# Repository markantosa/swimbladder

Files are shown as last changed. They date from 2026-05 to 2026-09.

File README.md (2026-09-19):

# SwimBladder

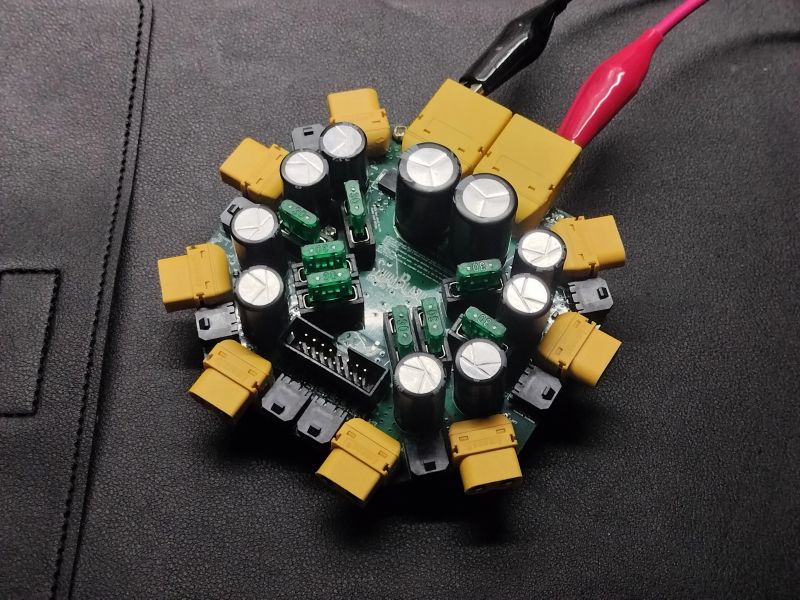
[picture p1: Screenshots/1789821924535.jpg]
Assembled SwimBladder PDB


Power distribution board (PDB) project files for the SwimBladder project.

Silkscreen tag: `SOAR UWU | 8 x T200 | V1.1`

> [!WARNING]
> This board is an unvalidated, untested work in progress (WIP).
> It has not completed electrical, thermal, or in-water system validation.
> Do not treat this design as production-ready hardware.

## Project Status

- Current state: WIP (design in progress)
- Revision: V1.1
- Validation status: not electrically validated
- Test status: not thermally validated, not full-load validated, not field-tested
- Use at your own risk until formal verification is completed

## Repository Contents

- `KiCad Project Files v1.1/` - **Canonical** KiCad project, PCB, schematic, and the
  `SwimBladder Custom Footprints` library. Open `KiCad Project Files v1.1/UWU PDB.kicad_pro`.
- `KiCad Project Files/` - Deprecated earlier project set, kept for history. Do not edit.
- `SwimBladder PDB.kicad_sch` (repo root) - Stale May snapshot, superseded by the schematic
  inside `KiCad Project Files v1.1/`. Do not use.
- `Screenshots/` - Board and schematic screenshots. `v1.1 *.png` are current; the unprefixed
  files are the earlier V1.0 captures.
- `SwimBladderV1.0.step` - 3D board model (V1.0 geometry).
- `Swim_Bladder_Doc_v3_0.pdf` - Full engineering reference and calculations. Component values
  in this PDF predate the V1.1 schematic changes listed below.

## Project Overview

This board is designed as a compact 8-thruster central star-node PDB for Blue Robotics T200
systems with 4S battery input. It is currently in a pre-validation state and should be treated
as a reference design draft.

- System topology: battery -> cable-side main fuse -> optional e-stop/contactor -> dual XT90 input -> central high-current node -> 8 fused ESC branches -> XT60 outputs
- Nominal battery voltage: 14.8 V (4S), full charge: 16.8 V
- Thruster design current: about 25 A each
- Total design current: 200 A (with burst targets up to around 280-300 A)
- Per-branch fuse target: 30 A

## Schematic Summary (V1.1)

### Input / central node
- Dual XT90 input connectors (`J1`, `J19`) feeding one common +VBAT star node, symmetrical wiring for current sharing.
- Bulk capacitance at the node: `C_MAIN1`, `C_MAIN2` = 4700 uF each.
- Input TVS: `D1` (`D_TVS`), 22-24 V standoff class for 4S. Recommended part: SMDJ22A
  (unidirectional, 3 kW, DO-214AB / SMC footprint, `Diode_SMD:D_SMC` or `D_SMC_HandSolder`).
- Rail bleed / discharge: `R_BLEED1` = 22 kOhm. Draws ~0.76 mA / ~13 mW continuously at full
  charge - trivial dissipation for a 0603, well within its power/voltage rating.
- Power/status LED: `D2` (`LED`) with series resistor `R_LED1` = 10 kOhm.

### Per-ESC branch (x8)
- Branch fuse: `F_ESC1..F_ESC8` = 30 A.
- Branch bulk cap: `C_ESC1..C_ESC8` = 1000 uF.
- Branch high-frequency cap: `C_HF1..C_HF8` = 1 uF.
- Output: `J3..J10`, XT60 per branch.
- Branch decoupling is now two caps (1000 uF + 1 uF). The earlier third per-branch cap
  (1 nF high-frequency) has been removed - on a high-current motor branch it contributes
  negligible benefit and can create anti-resonance with the larger caps.

### PWM signal
- 16-pin IDC header `J2` (`Conn_02x08_Odd_Even`, 2x8, 2.54 mm), alternating PWM / GND pins.
  Suggested part footprint: `Connector_IDC:IDC-Header_2x08_P2.54mm_Vertical`.
- Individual PWM channel inputs: `J11..J18` (PWM1..PWM8).
- Per-channel series resistor: `R_PWM1..R_PWM8` = 100 Ohm.
- Per-channel pulldown resistor: `R_PD1..R_PD8` = 10 kOhm.

## Passive Footprint Notes

- PWM channel series resistors (`R_PWM*`): 0402 hand-solder land pattern
  (`Resistor_SMD:R_0402_1005Metric_Pad0.72x0.64mm_HandSolder`) for IDC header pitch.
- All other signal passives (`R_BLEED1`, `R_LED1`, `R_PD*`) and branch HF caps: 0603
  hand-solder (`R_0603_1608Metric_Pad0.98x0.95mm_HandSolder` /
  `C_0603_1608Metric_Pad1.08x0.95mm_HandSolder`).
- Custom / project-specific footprints live in `KiCad Project Files v1.1/SwimBladder Custom Footprints`.

## Key Engineering Notes (from the PDF)

- Architecture: single compact central +VBAT node, not dual banks, for a roughly 90 mm x 90 mm board.
- Safety: main fuse should be upstream on the battery cable (recommended 225-250 A), close to the battery.
- Copper strategy: use a short, wide, via-stitched central polygon (L1 + L3 for +VBAT), and strong common ground return (L2 + L4).
- Copper thickness for the 200 A / 300 A rating: 1 oz (35 um) is not sufficient. Spec 2 oz
  (70 um) minimum on the outer layers, 3 oz preferred, and carry +VBAT and GND on two layers
  each in parallel (~4 oz-equivalent per net) with dense inter-layer via stitching. Treat the
  central node as a plane, not a trace, and size pours/vias for <= 20-30 C rise. Per-branch
  (~25 A): 2 oz outer with ~10-15 mm pour width is adequate.
- Via stitching: use two via classes - large power vias (~1.2 mm pad / 0.6 mm drill or bigger)
  for the +VBAT node and ground return, and a smaller class (~0.6-0.8 mm pad / 0.3-0.4 mm drill)
  for signal-ground / thermal stitching around the PWM header.
- Branch geometry: practical branch widths around 12-15 mm (8-10 mm absolute compact minimum for very short sections).
- Connectors: dual XT90 input for current sharing (symmetrical wiring), XT60 per ESC branch preferred.
- Protection/passives: 22-24 V standoff TVS class for 4S input, bulk capacitance near input/node plus branch-level capacitors.
- Signal: 16-pin IDC PWM header with alternating PWM/GND and per-channel series + pulldown resistors.

## Known Issues / TODO (V1.1)

- No outstanding items. TVS placement, input HF cap grouping, indicator LEDs, and the
  `R_BLEED1` value (now 22 kOhm) have all been resolved.

## Quick Calculation Snapshot

- Per thruster power at 16 V and 25 A: 400 W
- System power for 8 thrusters: 3200 W
- Example central copper section in the doc (50 mm width, 140 um thickness, 25 mm length, one layer):
	- Estimated R ~= 0.0616 mOhm
	- Vdrop at 200 A ~= 0.012 V
	- Copper loss at 200 A ~= 2.46 W

For complete assumptions, formulas, BOM guidance, and test plan, see `Swim_Bladder_Doc_v3_0.pdf`.

## Screenshots (V1.1)

| Assembled Board (1) | Assembled Board (2) |
|---|---|
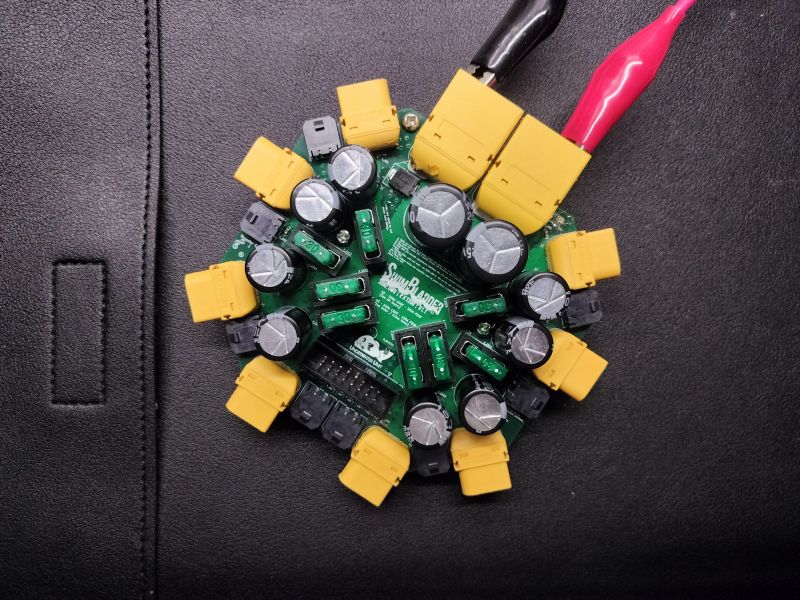
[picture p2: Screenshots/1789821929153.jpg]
Assembled SwimBladder PDB, angle 2
| Assembled SwimBladder PDB, angle 1 |  |

| Routing | 3D Render - Top | 3D Render - Isometric |
|---|---|---|
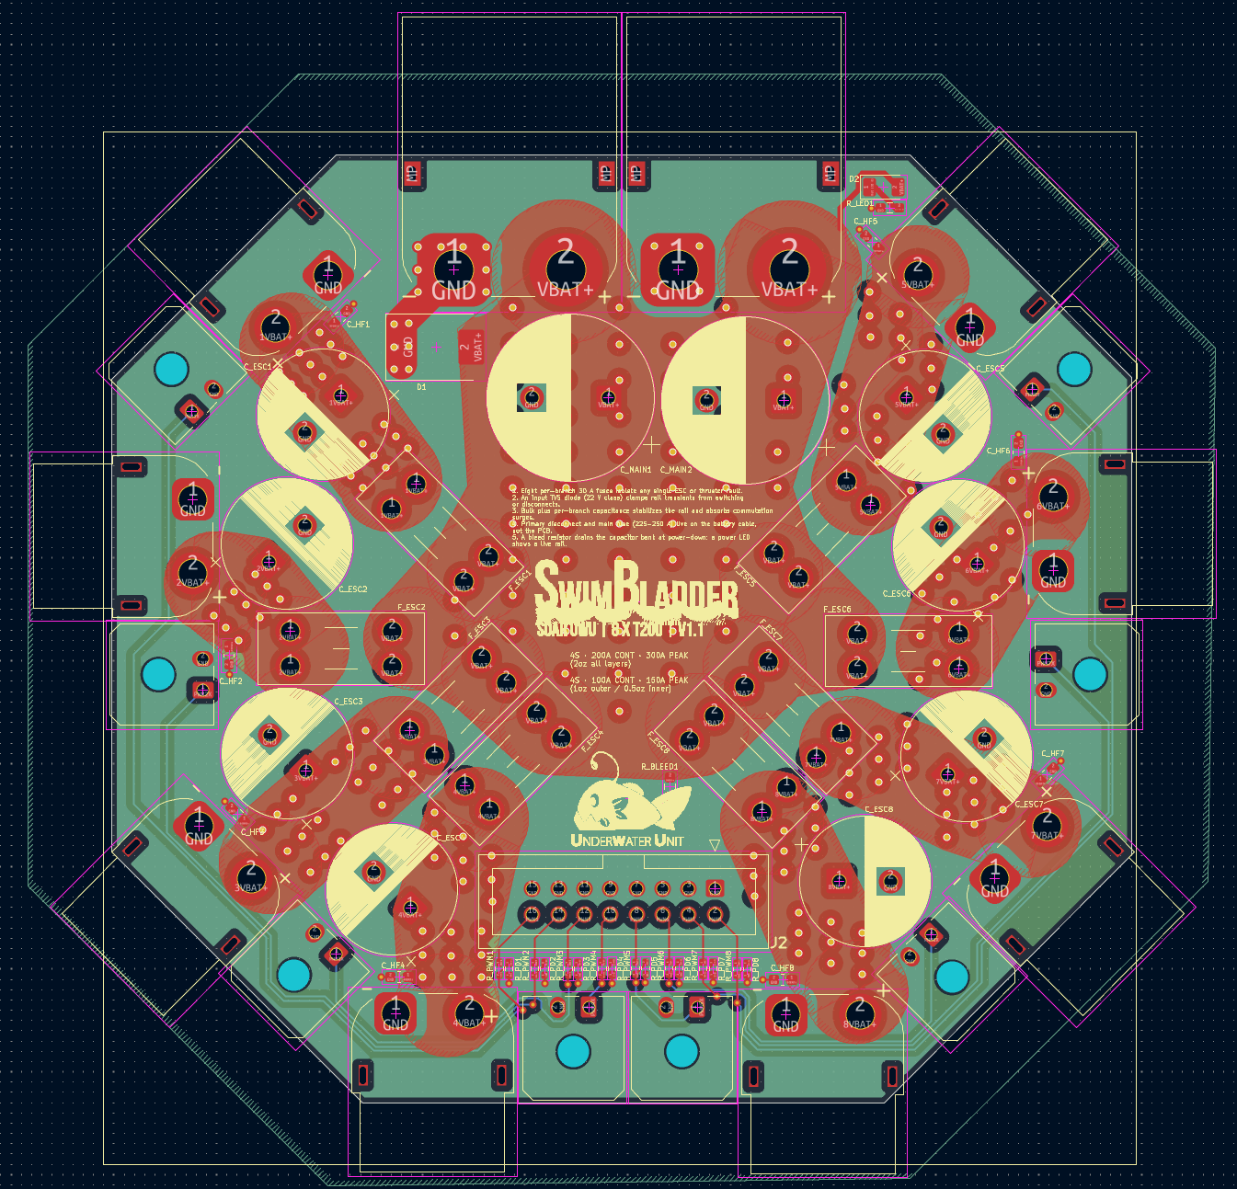
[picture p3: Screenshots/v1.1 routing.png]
V1.1 routing
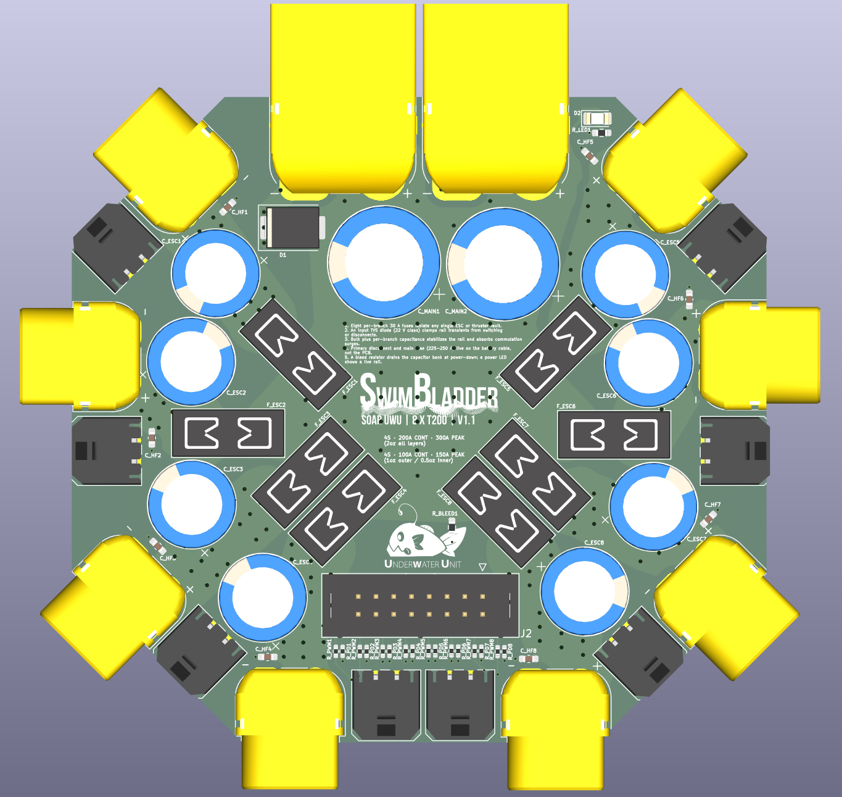
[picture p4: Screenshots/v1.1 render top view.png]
V1.1 render, top view
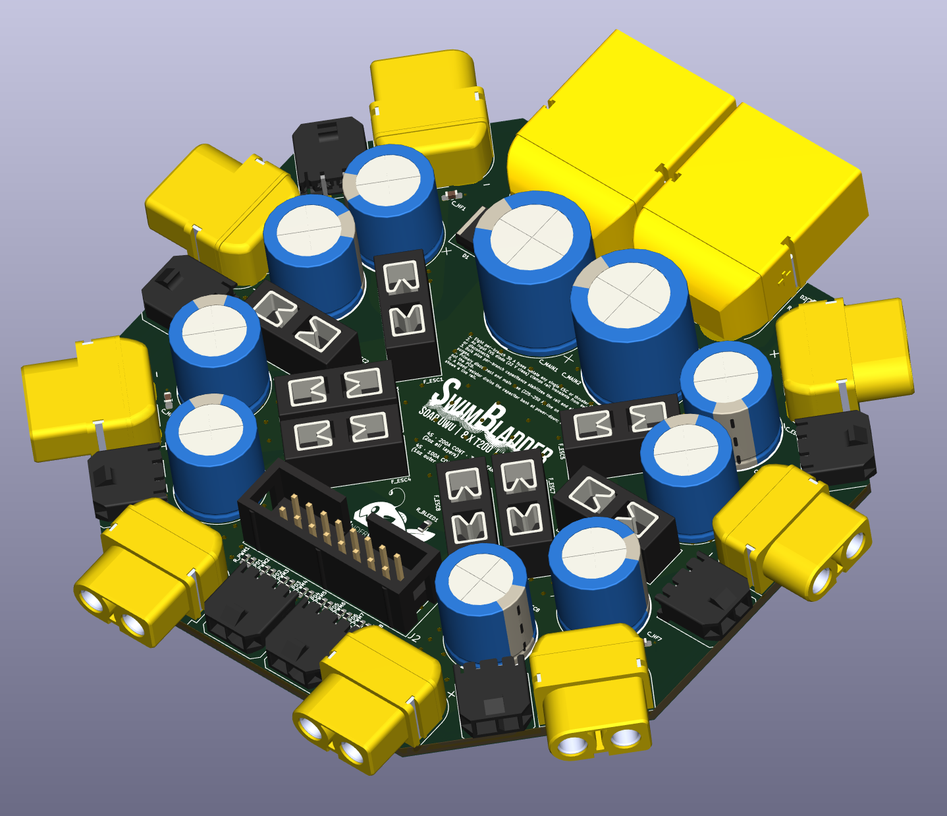
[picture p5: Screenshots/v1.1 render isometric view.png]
V1.1 render, isometric view
|  |  |  |

<sub>Earlier V1.0 captures (`Schematic.png`, `PCB Editor View.png`, `3D View.png`) remain in `Screenshots/` for reference.</sub>

## Getting Started

1. Install KiCad (recommended version 8+).
2. Open the project from `KiCad Project Files v1.1/UWU PDB.kicad_pro`.
3. Review schematic, layout, and engineering assumptions from the PDF before fabrication,
   noting the V1.1 changes and open TODO items above.

## Changelog

### V1.1 (in progress)
- Canonical project files moved to `KiCad Project Files v1.1/`; earlier `KiCad Project Files/`
  and the repo-root `SwimBladder PDB.kicad_sch` are deprecated.
- Added `SwimBladder Custom Footprints` library.
- Main bulk capacitance specified as `C_MAIN1/2` = 4700 uF each.
- Removed the 1 nF per-branch decoupling cap; branches now use 1000 uF + 1 uF only.
- PWM front-end defined: `R_PWM*` = 100 Ohm series, `R_PD*` = 10 kOhm pulldown, inputs `J11..J18`.
- Added rail bleed resistor `R_BLEED1` (value still a placeholder) and status LED `D2` / `R_LED1`.
- Input TVS `D1` present; placement correction pending (see Known Issues).

### V1.0
- Initial 8-branch central star-node PDB layout.

## Procurement (2-board build)

Bare PCB via JLCPCB; most components via LCSC (`SwimBladder_LCSC_BatchBOM_v1.1.csv`); full
reference BOM in `SwimBladder_BOM_v1.1.csv`. JLCPCB and LCSC ship separately even though they're
sister companies - no combined-box option outside of paying for JLC's PCBA assembly service.

### Still need to source separately (not in the LCSC batch order)
- [ ] `R_BLEED1`, 22k Ohm, 0603 (LCSC C114065) - MOQ is Min:100/Mult:100, not worth it for ~3
  pieces; ask around for spares or buy loose.
- [ ] `R_LED1` + `R_PD1..R_PD8`, 10k Ohm, 0603 (LCSC C98220) - same MOQ issue, ~23 pieces needed.
- [ ] 30 A mini blade fuse elements (x16) for `F_ESC1..F_ESC8` - these plug into the Keystone 3568
  holder (which is in the LCSC order) but the fuse element itself isn't an LCSC/electronics-
  distributor item; source from an automotive parts store or RC supplier.
- [ ] `F_ESC1..F_ESC8` fuseholders, Keystone 3568 (x8) - LCSC C5249699 was out of stock, dropped
  from the batch order; source from Digi-Key/Mouser instead.

### Already owned, not in the order
- `D2` status LED
- `J2` IDC 2x08 header
- `R_PWM1..R_PWM8`, 100 Ohm, 0402 (from sample book)

## License

This project is licensed under the MIT License. See the LICENSE file for details.

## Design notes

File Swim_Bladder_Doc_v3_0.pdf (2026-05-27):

Compact 8-Thruster Star-Node T200 PDB Technical Specification | 1

## Swim Bladder: 8-Thruster Central Star-Node PDB

Technical Specification for 8× Blue Robotics T200 + Basic ESC System

Power Source: 4S battery direct input, 14.8 V nominal / 16.8 V fully charged Architecture: Cable-side main fuse, dual XT90 input, one compact central high-current node, eight fused ESC branches

Contents

1 Purpose of This Architecture | 2
2 Electrical Assumptions | 2
3 High-Level System Architecture | 3
4 Recommended Physical Layout | 3
5 Fuse Architecture | 4
6 PCB Stack-Up | 5
7 Copper Geometry and Current Carrying Design | 5
8 Voltage Drop and Loss Estimates | 6
9 Via Specification | 7
10 Connector Recommendations | 7
11 Passive Components and Protection | 8
12 PWM and Signal Architecture | 9

Compact 8-Thruster Star-Node T200 PDB Technical Specification | 2
13 Recommended BOM | 9
14 Layout Checklist | 9
15 Test Plan | 10
16 Final Design Summary | 11

### 1 PURPOSE OF THIS ARCHITECTURE

This document describes a compact high-current power distribution board for an 8-thruster ROV system using eight Blue Robotics T200 thrusters and eight Basic ESCs powered directly from a 4S lithium battery. The previous dual-bank architecture was useful for larger boards, but for a compact board of approximately 90 mm by 90 mm, the two bank nodes physically merge into the same central copper region.

The recommended compact architecture is therefore a single central star node: the battery input feeds a very short, wide, heavily via-stitched copper island, and all eight branch fuses are placed close to that node.

Recommended compact architecture:

Battery -> cable-side main fuse -> e-stop/contactor -> dual XT90 input -> short central 200 A node
-> eight 30 A branch fuses
-> eight XT60 ESC outputs

Design Note: The board is no longer treated as two separated 4-thruster banks. Instead, it is treated as one compact star PDB. This is acceptable because the main fuse is moved upstream on the cable and the high-current PCB region is extremely short.

Warning: This architecture depends on having a proper upstream main fuse near the battery. Without a main cable-side fuse, the central node and PCB input copper before the branch fuses would be insufficiently protected.

### 2 ELECTRICAL ASSUMPTIONS

A 4S lithium battery is assumed:

Vnominal ≈ 14.8 V | (1)
Vfull = 4 × 4.2 V = 16.8 V | (2)

Use conservative T200 current at the 16 V class:

Ithruster,max ≈ 25 A | (3)

For eight thrusters:

Itotal,max = 8 × 25 A = 200 A | (4)

Recommended system design target:

Icentral node,continuous design = 200 A–220 A | (5)
Icentral node,burst design = 280 A–300 A | (6)
Ibranch,design = 30 A | (7)

Per-thruster electrical power at 16 V:

Pthruster = V I = 16 V × 25 A = 400W | (8)

Compact 8-Thruster Star-Node T200 PDB Technical Specification | 3

Whole system:

Psystem = 8 × 400W = 3200W | (9)

### 3 HIGH-LEVEL SYSTEM ARCHITECTURE

### 3.1 Recommended Power Tree

4S Battery, 14.8 V nominal / 16.8 V full
[Main fuse on cable, near battery: 225-250 A typical]
[Electrical E-stop / DC contactor, optional but recommended] |
[Dual XT90-S or dual XT90 input to PCB]
[Short central 200 A star node]
|-- 30 A fuse -- XT60 -- ESC1 -- T200 |-- 30 A fuse -- XT60 -- ESC2 -- T200 |-- 30 A fuse -- XT60 -- ESC3 -- T200 |-- 30 A fuse -- XT60 -- ESC4 -- T200 |-- 30 A fuse -- XT60 -- ESC5 -- T200 |-- 30 A fuse -- XT60 -- ESC6 -- T200 |-- 30 A fuse -- XT60 -- ESC7 -- T200 ‘-- 30 A fuse -- XT60 -- ESC8 -- T200

### 3.2 Core Layout Principle

The central node architecture minimizes PCB area by reducing the length of copper carrying full system current.

Bad compactness:
Battery input -> long 200 A spine -> ESC1 -> ESC2 -> ... -> ESC8

Good compactness:
Battery input -> short 200 A copper node -> eight short 30 A branches

Warning: The central node should be designed as a copper bus plate built into the PCB, not as a normal routed trace. It must be short, wide, multi-layered, heavily via-stitched, and thermally tested.

### 4 RECOMMENDED PHYSICAL LAYOUT

### 4.1 Top-Level Board Layout

For a compact 90 mm by 90 mm PCB, place the dual XT90 input close to the center or edge-center of the board, then place the eight branch fuse inputs as close as possible around the central node.

Top view concept, compact central-node version:

DUAL XT90 BATTERY INPUT
XT90-A XT90-B
\ /
\ /
+---------------------+
| CENTRAL 200 A NODE |
+---------------------+
/ / / | \ \ \
F1 F2 F3 F4 F5 F6 F7/F8
X1 X2 X3 X4 X5 X6 X7/X8
E1 E2 E3 E4 E5 E6 E7/E8

X1-X8 = XT60 branch outputs
E1-E8 = ESC power leads
PWM IDC connector should sit near a quiet board edge.

### 4.2 Central Node Detail

The central node is a compact copper island connecting the dual XT90 positive inputs to all eight branch fuse inputs.

Dual XT90 positive pads
+----------------+
| 200 A NODE | short, wide, via-stitched copper island
+----------------+
/ / / / \ \ \ \
F1 F2 F3 F4 F5 F6 F7 F8
XT60 branch outputs to ESCs

Compact 8-Thruster Star-Node T200 PDB Technical Specification | 4

Design Note: The branch split should happen immediately after the dual XT90 input. The central node should feed all fuse input pads directly with no thin neck-downs.

### 4.3 Ground Layout

The positive side uses a central star node and individual branch fuses. The ground side should be a common, low-impedance return system.

Battery - from dual XT90 input
+-- common GND plane / GND node
|-- XT60 negative return for ESC1-ESC8
‘-- flight controller signal ground reference

Design Note: Use common GND across the board. ESC PWM signals require a common reference to the flight controller. Do not isolate grounds unless there is a specific measurement reason.

### 5 FUSE ARCHITECTURE

### 5.1 Fuse Philosophy

Recommended protection hierarchy:

- main fuse on cable, close to the battery,
- optional contactor or electrical e-stop before the PCB,
- one branch fuse per ESC on the PCB.

### 5.2 Cable-Side Main Fuse

Because the PCB no longer contains bank fuses, the upstream cable-side main fuse becomes mandatory.

Recommended:

Imain fuse = 225 A–250 A | (10)

Placement:

Battery + → main fuse → e-stop/contactor → PCB input | (11)

Recommended fuse type:

- ANL fuse,
- MEGA fuse,
- high-current marine or EV-style battery fuse holder.

Warning: The main fuse must be close to the battery, not only close to the PCB. Its job is to protect the battery cable, e-stop wiring, PCB input, and central node from catastrophic shorts before the branch fuses.

### 5.3 Branch Fuse Sizing

Each ESC branch:

Ibranch actual ≈ 24 A–25 A | (12)
IESC class ≈ 30 A | (13)

Recommended:

Ibranch fuse = 30 A | (14)

Recommended fuse holder:

- Keystone 3568 mini blade fuse holder, PCB-mounted, or
- Littelfuse FLR 178.6165 ATO holder with caution, or
- off-board inline ATO/ATC fuse holder for better thermal margin.

Warning: Do not increase branch fuses above 30 A unless the ESC, wiring, connector, and thermal path are explicitly validated. If nuisance blowing occurs, investigate throttle limiting, cooling, and fuse time-current curves first.

Compact 8-Thruster Star-Node T200 PDB Technical Specification | 5

### 6 PCB STACK-UP

Recommended 4-layer stack-up:

Table 1: Recommended 4-Layer Stack-Up

Layer | Function
L1 / F.Cu | +VBAT central node and branch fuse input/output pours
L2 / In1.Cu | GND high-current return plane
L3 / In2.Cu | +VBAT central node and branch pours, stitched to L1
L4 / B.Cu | GND plane + PWM / telemetry / low-current signal routing
+V BAT path : L1 + L3 | (15)
GND path : L2 + L4 | (16)

Design Note: Use L1 and L3 in parallel for the central +VBAT node and branch paths. Use L2 and L4 in parallel for the common GND return.

### 7 COPPER GEOMETRY AND CURRENT CARRYING DESIGN

### 7.1 Estimation Method

Use IPC-style estimation:

I = k∆T

bA

c
(17)

Rearranged:

A =

I
k∆Tb

1/c
(18)

Common constants:

kexternal = 0.048, | kinternal = 0.024, | b = 0.44, | c = 0.725 | (19)

For 4 oz copper:

| tCu ≈ 140 µm | | | (20)

### 7.2 Branch Width

Each branch is designed for:

Ibranch design = 30 A | (21)

Estimated minimum 4 oz external copper width at approximately 20 ◦C rise:

W30A ≈ 5.4 mm | (22)

Recommended practical branch pour width:

Wbranch = 12 mm–15 mm | (23)

Absolute compact minimum for very short branch routes:

Wbranch,min ≈ 8 mm–10 mm | (24)

Compact 8-Thruster Star-Node T200 PDB Technical Specification | 6

### 7.3 Central Node Size

The central node carries full system current only over a very short distance.

Central node design target:

Inode,max = 200 A | (25)
Inode,design = 200 A–220 A | (26)
Inode,burst = 280 A–300 A | (27)

For a long one-layer 4 oz trace, 200 A would require a very large width. However, this board uses a compact multi-layer copper island rather than a long trace. The design goal is therefore:

Table 2: Recommended Central Node Geometry

Parameter | Recommendation
Node type | Large compact copper polygon, not a routed trace
Node location | Immediately after dual XT90 input pads
Node layers | L1 + L3 parallel +VBAT copper
Node length | As short as possible; preferably below 20 mm–30 mm before branch split
Node area | Maximize available area around XT90 and fuse inputs
Minimum effective copper section | Avoid any local neck-down below approximately 50 mm equivalent where full
current flows
Via stitching | Dense via field across the node and around every input/fuse pad
Branch exits | Eight direct short branch pours from node to branch fuses
Copper exposure | Optional exposed copper/solder reinforcement on central node if fabrication al-
lows

Warning: Do not draw a thin trace from the XT90 input to the fuse inputs. The central node should be a filled polygon surrounding the input pads and fuse input pads.

### 7.4 Input Connector Sharing

Using dual XT90 inputs helps share current between two physical connectors. The two XT90 positive pads should join immediately into the central node. The two XT90 negative pads should join immediately into the common GND plane.

Iper XT90,ideal ≈

200 A
2
= 100 A | (28)

Warning: Current sharing between two connectors is not automatically perfect. Keep both input paths sym-metrical, short, and wide. Use the same wire gauge and length for both XT90 feeds if possible.

### 8 VOLTAGE DROP AND LOSS ESTIMATES

For a short central node, losses can be manageable despite high current. Example: 50 mm effective-width, 140 µm thick, 25 mm long copper section on one layer:

A = 0.050 × 0.000140 = 7.0 × 10⁻⁶ m² (29)

R =

1.724 × 10⁻⁸ × 0.025
7.0 × 10⁻⁶

(30)

≈ 0.0000616 Ω = 0.0616 mΩ | (31)

At 200 A:

Vdrop = IR = 200 × 0.0000616 ≈ 0.012 V | (32)

Ploss = I

2R = 200² × 0.0000616 ≈ 2.46W | (33)

Compact 8-Thruster Star-Node T200 PDB Technical Specification | 7

With L1 and L3 sharing current, effective resistance can be lower if the vias are dense and current spreads well. In practice, pad bottlenecks, solder joints, fuse holders, and connector interfaces may dominate heating.

Design Note: The central-node layout reduces heating mainly by reducing the length of copper that carries full system current. After the node splits, each branch only carries approximately 25 A–30 A.

### 9 VIA SPECIFICATION

### 9.1 Recommended Via Dimensions

Table 3: Recommended Via Dimensions

Parameter | Recommended | Notes
Via drill | 0.5 mm–0.6 mm | Larger preferred if fab allows
Via diameter | 1.0 mm–1.2 mm | Use for high-current stitching
Same-net via pitch | 1.5 mm–2.5 mm | Use arrays across node and branches
Different-net clearance | ≥ 1.0 mm preferred | Especially near node and connector regions

### 9.2 Recommended Via Counts

Table 4: Via Counts for Compact Central-Node Design

Location | +VBAT Vias | GND Vias | Notes
Dual XT90 input region | 80+ total | 80+ total | Around both positive and negative input pads
Central 200 A node | 100+ distributed | 100+ nearby GND stitching | Dense via field across the node
Each branch exit from node | 8–12 | 8–12 | Per branch exit
Each ESC branch | 12–20 | 12–20 | Per branch
Each XT60 connector region | 12–16 | 12–16 | Prevent pad bottlenecks
Capacitor region | 6–10 | 6–10 | Short path to planes
TVS region | 12–20 | 12–20 | Low-impedance clamp path

Warning: Distribute vias across the node. Do not place only one via cluster; the goal is current spreading between L1 and L3 across the whole copper node.

### 10 CONNECTOR RECOMMENDATIONS

### 10.1 Main Battery Input

For compactness, the current design uses dual XT90 input connectors. This is acceptable if the upstream wiring is symmetric and the main fuse is on the cable.

Table 5: Main Input Connector Options

Connector | Verdict
Dual XT90-S | Good compact option if current shares symmetrically.
QS8-S | Preferred single high-current connector if packaging allows.
AS150 or AS150U | Good high-current anti-spark option.
M6 or M8 ring lug / stud input | Most mechanically robust option, but larger.
Single XT90-S | Not preferred for full 8-thruster 4S operation.

### 10.2 ESC Output Connectors

At 4S, each ESC branch is expected to operate around 25 A and should be designed around 30 A. XT60 is preferred for each branch output.

Compact 8-Thruster Star-Node T200 PDB Technical Specification | 8

Table 6: ESC Output Connector Options

Connector | Verdict
XT60 | Preferred for branch-level margin and lower connector heating.
XT30 | Borderline; use only if short, well-soldered, cooled, and thermally validated.
Direct terminal, ring, or spade | Mechanically robust if packaging allows.

Design Note: Horizontal XT60 connectors may be placed directly beside the central node area, but each XT60 must be behind its own branch fuse. Do not feed multiple ESCs through one XT60.

### 11 PASSIVE COMPONENTS AND PROTECTION

### 11.1 Capacitors

Recommended capacitor placement follows the central-node architecture:

- main bulk capacitor near the dual XT90 input or central node,
- branch bulk capacitors near each XT60/ESC output,
- ceramic capacitors near branch outputs for high-frequency decoupling.

Main node capacitance:

Cmain bulk = 2200 µF–4700 µF, 35 V or 50 V | (34)

Space-saving alternatives:

Cmain alternative = 2 × 2200 µF or 3 × 1500 µF | (35)

Per ESC branch:

Cbranch bulk = 470 µF–1000 µF, 35 V or 50 V | (36)
CHF = 1 µF, 50 V, X7R | (37)
Cdecouple = 100 nF, 50 V, X7R | (38)

Recommended compact capacitor footprints:

- 1000 µF, 35 V: Capacitor_THT:CP_Radial_D8.0mm_P3.50mm if exact part fits, otherwise D10.0mm_P5.00mm;
- 4700 µF, 35 V: Capacitor_THT:CP_Radial_D12.5mm_P5.00mm if exact part fits;
- ceramic capacitors: Capacitor_SMD:C_1206_3216Metric preferred.

### 11.2 TVS Protection

For a 4S pack, the TVS must not conduct during normal fully charged battery voltage of 16.8 V. Recommended:

VTVS standoff = 22 V–24 V | (39)

Recommended part class:

- SMCJ24A or similar for compact protection,
- SM8S24A or similar for stronger surge margin if space allows.

KiCad symbol and footprint:

- symbol: Device:D_TVS,
- footprint: Diode_SMD:D_SMC for SMCJ class.

Wiring:

TVS cathode → +V BAT | (40)
TVS anode → GND | (41)

Warning: The TVS should be close to the input/central node, but it must not create a narrow bottleneck in the main current path. Prioritize a clean central copper node.

Compact 8-Thruster Star-Node T200 PDB Technical Specification | 9

### 11.3 Bleeder Resistor

Recommended:

Rbleeder = 10 kΩ–47 kΩ | (42)
Prating = 0.25W minimum | (43)

At 16.8 V and 10 kΩ:

P =

16.8

2
10000
= 0.028W | (44)

### 11.4 Power Indicator LED

LED resistor at full charge for approximately 2 mA:

R =

16.8 − 2
0.002
= 7.4 kΩ | (45)

Recommended:

RLED = 6.8 kΩ–10 kΩ, 0.25W | (46)

### 12 PWM AND SIGNAL ARCHITECTURE

PWM is low-current and distributed through one 16-pin IDC connector.

Table 7: 16-Pin IDC PWM Pinout

Pin | Signal | Pin | Signal
1 | PWM1 | 2 | GND
3 | PWM2 | 4 | GND
5 | PWM3 | 6 | GND
7 | PWM4 | 8 | GND
9 | PWM5 | 10 | GND
11 | PWM6 | 12 | GND
13 | PWM7 | 14 | GND
15 | PWM8 | 16 | GND

Per PWM channel:

Rseries = 100 Ω–220 Ω | (47)
Rpulldown = 10 kΩ | (48)

Recommended:

Rseries = 100 Ω, | Rpulldown = 10 kΩ | (49)

Design Note: Keep the IDC connector near a quiet board edge. Route PWM away from the dual XT90 input, TVS diode, fuse input pads, and central node.

### 13 RECOMMENDED BOM

### 13.1 Power Path BOM

### 13.2 Passive and Protection BOM

### 13.3 Signal BOM

### 14 LAYOUT CHECKLIST

Compact 8-Thruster Star-Node T200 PDB Technical Specification | 10

Table 8: Power Path Components for Compact Central-Node Design

Ref. | Component | Rating / Value | Qty
J-IN-A/B | Main input connectors | Dual XT90-S or dual XT90 | 2
F-MAIN | Cable-side main fuse | 225 A–250 A, DC-rated | 1 off-PCB
K-ESTOP | Optional contactor / e-stop | 200 A+ DC contactor, 12 V coil typical | 1 off-PCB
J-ESC-1–8 | ESC output connector | XT60 preferred; XT30 derated | 8
F-ESC-1–8 | Branch fuse | 30 A mini blade / ATO / ATC | 8

Table 9: Passive and Protection Components

Ref. | Component | Rating / Value | Qty
C-MAIN | Main bulk capacitor | 2200 µF–4700 µF, 35 V or 50 V | 1–2
C-ESC-1–8 | Branch electrolytic capacitor | 470 µF–1000 µF, 35 V or 50 V | 8
C-HF-1–8 | Ceramic capacitor | 1 µF, 50 V, X7R | 8
C-DEC-1–8 | Ceramic capacitor | 100 nF, 50 V, X7R | 8
D-TVS-MAIN | Main TVS diode | 22 V–24 V standoff, high pulse power | 1
R-BLEED | Bleeder resistor | 10 kΩ, 0.25W | 1
LED-MAIN | Main power LED | suitable indicator LED | 1
R-LED | LED resistor | 6.8 kΩ–10 kΩ, 0.25W | 1

Table 10: PWM Signal Components

Ref. | Component | Rating / Value | Qty
J-PWM | IDC connector | 2 by 8, 16-pin | 1
R-PWM-1–8 | Series resistor | 100 Ω | 8
R-PD-1–8 | Pull-down resistor | 10 kΩ | 8
D-ESD | Optional ESD diode array | Low-capacitance signal ESD | 1–2
- Cable-side main fuse is included near the battery.
- E-stop / contactor is upstream of PCB if used.
- Dual XT90 inputs are short and symmetric.
- Central node is a large filled polygon, not a trace.
- No long 200 A spine exists.
- All branch fuse inputs connect directly to the central node.
- Eight branch fuses are placed close to the node.
- Each branch fuse is rated 30 A.
- Each XT60 is behind its own branch fuse.
- Branch pours are 12 mm–15 mm where possible.
- Absolute branch bottlenecks are not below 8 mm– 10 mm unless extremely short.
- High-current pads use direct copper connection.
- No thermal reliefs on XT90, fuse, XT60, TVS, or bulk capacitor pads.
- L1/L3 +VBAT copper is heavily stitched.
- L2/L4 GND copper is heavily stitched.
- GND is common and low impedance.
- TVS does not block or neck the main current path.
- PWM traces stay away from input, fuses, TVS, and central node.
- IDC pinout alternates PWM/GND.
- Cable strain relief is included for XT90 and XT60 wiring.
- Thermal camera test is planned.

### 15 TEST PLAN

### 15.1 Continuity Test

Before applying power:

- verify +VBAT to GND is not shorted,
- verify each branch positive passes through its branch fuse,
- verify each ESC negative returns to common GND,

Compact 8-Thruster Star-Node T200 PDB Technical Specification | 11
- verify dual XT90 positive inputs join at the central node,
- verify dual XT90 negative inputs join at common GND,
- verify PWM lines are not shorted to +VBAT,
- verify IDC pinout.

### 15.2 Low-Current Power-Up

Use a current-limited bench supply:

Vsupply = 16 V–16.8 V | (50)
Ilimit = 0.5 A–1 A | (51)

Check:

- power LED turns on,
- no unexpected heating,
- capacitors charge normally,
- TVS does not heat during normal supply voltage.

### 15.3 Progressive Load Test

Test progressively:

1. 1 ESC at low throttle.
2. 1 ESC at high throttle.
3. 2 ESCs.
4. 4 ESCs.
5. 8 ESCs with controlled ramp.

Measure:

- input current,
- current through each XT90 input if possible,
- voltage drop from XT90 input to each XT60 connector,
- temperature of central node,
- temperature of branch fuse holders,
- temperature of XT60 pads,
- temperature of XT90 pads,
- TVS temperature,
- PWM stability during throttle changes.

Suggested pass criteria:

- no copper node above approximately 60 ◦C–70 ◦C during expected operation,
- no connector or fuse holder hotspot significantly above surrounding copper,
- voltage drop from input to XT60 branch preferably below 100 mV–200 mV under heavy load,
- dual XT90 inputs share current reasonably well,
- no PWM glitches during high-current throttle changes.

### 16 FINAL DESIGN SUMMARY

Design Note: For a compact 90 mm by 90 mm PCB, the single central star-node architecture is more practical than forcing two artificial banks. The safety condition is that the main fuse must be on the cable near the battery, while each ESC branch remains individually fused on the PCB.

Compact 8-Thruster Star-Node T200 PDB Technical Specification | 12

Table 11: Recommended Parameters for Compact Central Star-Node Architecture

Item | Recommendation
Battery input | 4S lithium, 14.8 V nominal, 16.8 V full
Architecture | One compact central 200 A star node with eight fused branches
Board size target | Approximately 90 mm by 90 mm
PCB | 4-layer, 4 oz copper preferred
Stack-up | L1 +VBAT, L2 GND, L3 +VBAT, L4 GND + PWM/signal
Main input | Dual XT90-S or dual XT90, symmetric wiring required
Main fuse | Off-PCB cable-side fuse, 225 A–250 A
E-stop | Off-PCB contactor or manual isolator before PCB
Branch fuses | 8× 30 A mini blade / ATO / ATC fuses
ESC outputs | XT60 preferred; XT30 only if derated and thermally validated
Central node | Short, wide copper polygon directly after dual XT90 input
Node length | Preferably below 20 mm–30 mm before branch split
Branch width | 12 mm–15 mm per ESC branch; 8 mm–10 mm compact minimum
Vias | 0.5 mm–0.6 mm drill / 1.0 mm–1.2 mm diameter preferred
Central node vias | 100+ +VBAT vias distributed across central node
Branch vias | 12–20 vias per branch per net
Main capacitance | 2200 µF–4700 µF, 35 V or 50 V
Branch capacitance | 8× 470 µF–1000 µF; 8× 1 µF; 8× 100 nF
TVS | Main TVS, 22 V–24 V standoff, SMCJ or stronger
PWM connector | 16-pin IDC, alternating PWM/GND
PWM passives | 100 Ω series + 10 kΩ pulldown per PWM channel
ESC cooling | External aluminium heat block

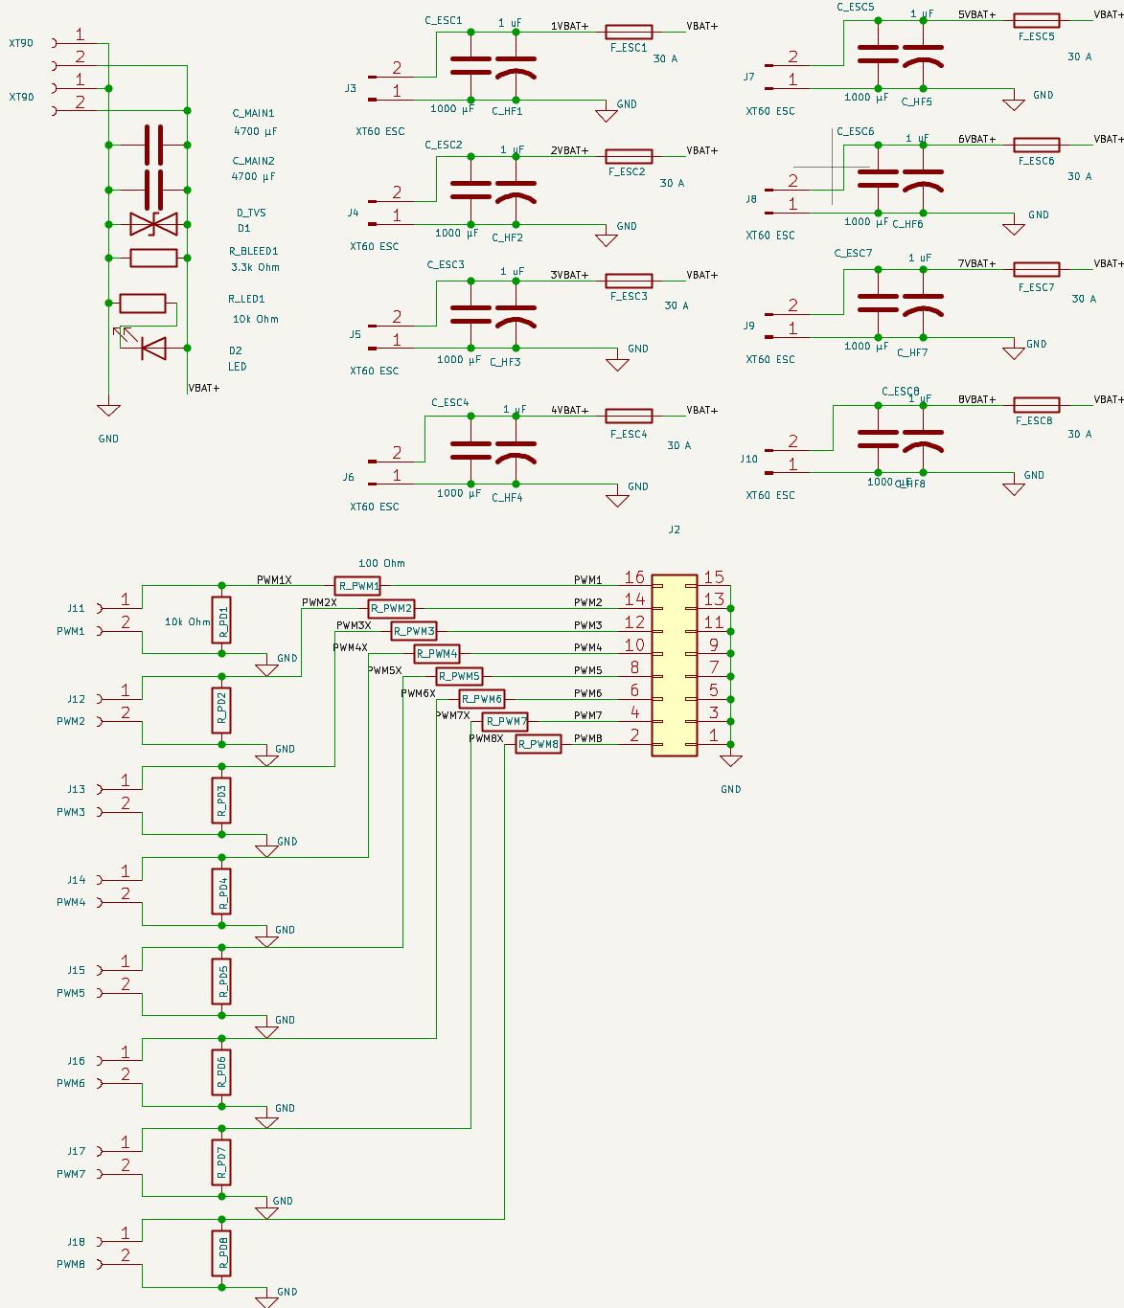
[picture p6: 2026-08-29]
Screenshots/v1.1 schematic.png

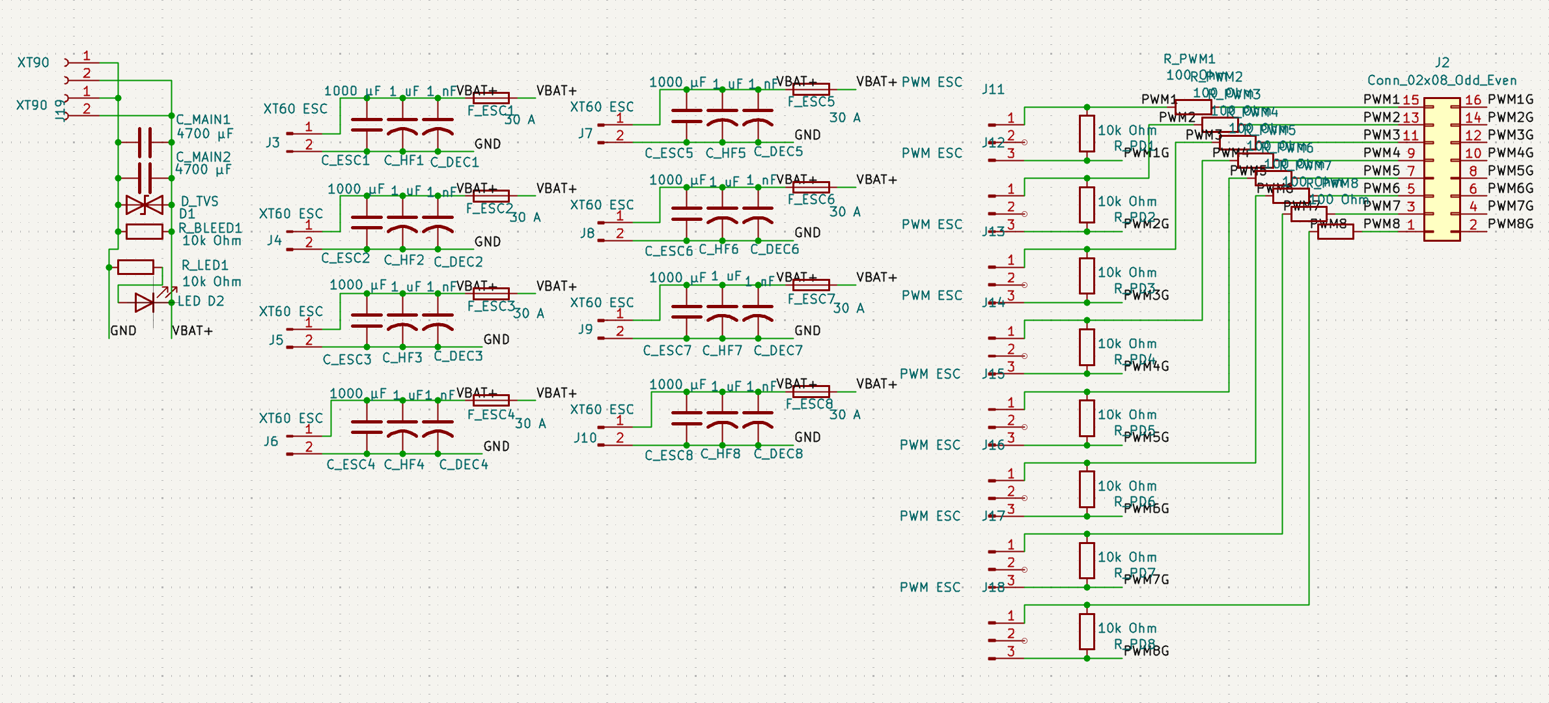
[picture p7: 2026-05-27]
Screenshots/Schematic.png

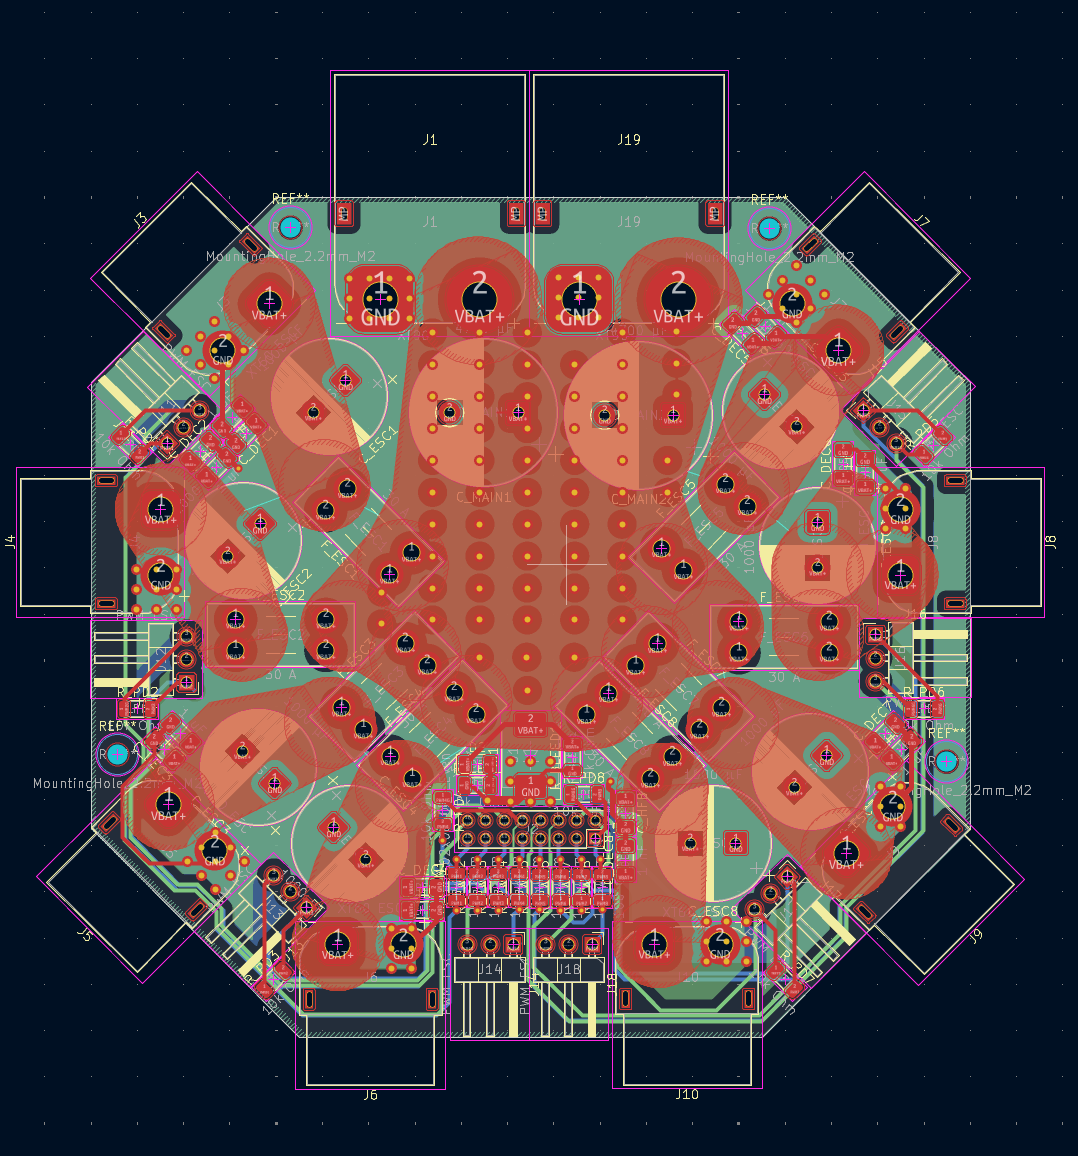
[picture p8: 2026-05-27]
Screenshots/PCB Editor View.png

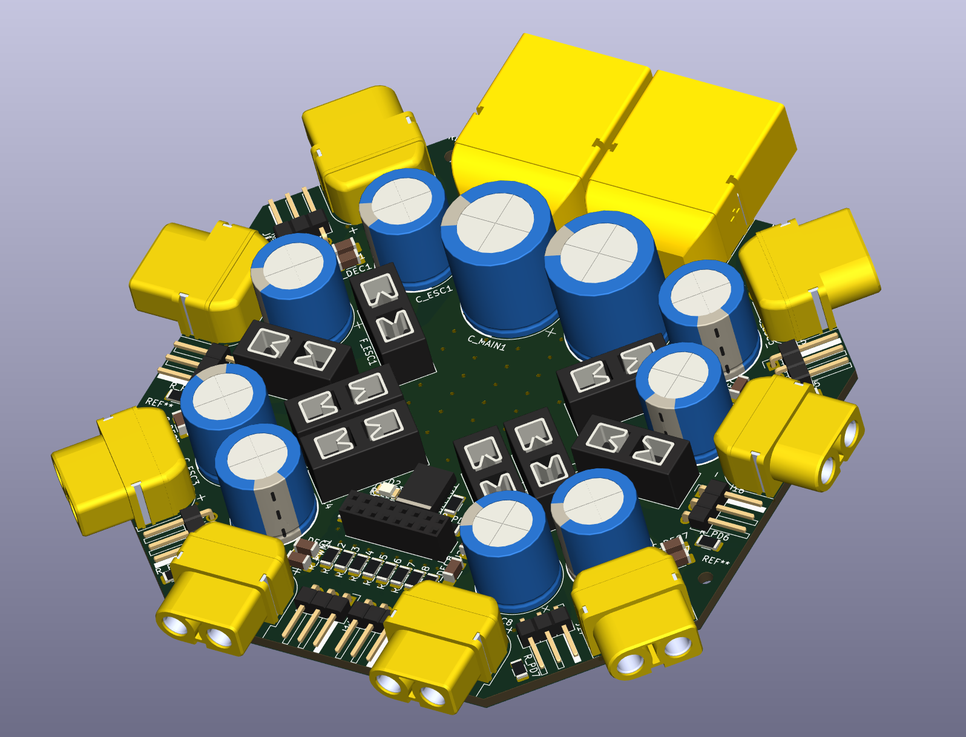
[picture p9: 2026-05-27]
Screenshots/3D View.png

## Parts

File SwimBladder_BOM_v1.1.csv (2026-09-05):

Designators | Value | Footprint | Qty per board | Order Qty (2 boards + margin/MOQ) | Package/Type | Source
J1, J19 | AMASS XT90PW-M.G.Y | Connector_AMASS:AMASS_XT90PW-M_1x02_P10.90mm_Horizontal | 2 | 4 | THT panel connector | LCSC C3040689
J3, J4, J5, J6, J7, J8, J9, J10 | AMASS XT60PW-F | Connector_AMASS:AMASS_XT60PW-F_1x02_P7.20mm_Horizontal | 8 | 16 | THT panel connector | LCSC C428722
J11, J12, J13, J14, J15, J16, J17, J18 | Molex 436500201 (Micro-Fit 3.0 43650-0200) | Connector_Molex:Molex_Micro-Fit_3.0_43650-0200_1x02_P3.00mm_Horizontal | 8 | 16 | THT 2-pin header | LCSC C587649
J2 | IDC Header 2x08 | Connector_IDC:IDC-Header_2x08_P2.54mm_Vertical | 1 | 0 | THT 16-pin IDC | ALREADY OWNED - not ordering
D1 | SMDJ22A TVS diode (5.0SMDJ22A/TR13 - Brightking) | Diode_SMD:D_SMC | 1 | 2 | SMC | LCSC C522679
D2 | Status LED | LED_SMD:LED_0805_2012Metric | 1 | 0 | 0805 | ALREADY OWNED - not ordering
C_MAIN1, C_MAIN2 | 4700uF 25V (EWH1EM472L25OT - AISHI) | Capacitor_THT:CP_Radial_D16.0mm_P7.50mm | 2 | 5 | Radial THT | LCSC C2843670 (Min:5 Mult:5, rounded up from 4)
C_ESC1, C_ESC2, C_ESC3, C_ESC4, C_ESC5, C_ESC6, C_ESC7, C_ESC8 | 1000uF 35V (35YXJ1000M12.5X20 - Rubycon) | Capacitor_THT:CP_Radial_D12.5mm_P5.00mm | 8 | 20 | Radial THT | LCSC C88743 (Min:5 Mult:5, rounded up from 16)
C_HF1, C_HF2, C_HF3, C_HF4, C_HF5, C_HF6, C_HF7, C_HF8 | 1uF 25V X7R (CL10B105KA8NNNC - Samsung) | Capacitor_SMD:C_0603_1608Metric_Pad1.08x0.95mm_HandSolder | 8 | 20 | 0603 | LCSC C29936 (Min:10 Mult:10)
F_ESC1, F_ESC2, F_ESC3, F_ESC4, F_ESC5, F_ESC6, F_ESC7, F_ESC8 (holder) | Keystone 3568 mini blade fuseholder | Fuse:Fuseholder_Blade_Mini_Keystone_3568 | 8 | 16 | THT fuseholder | NOT ORDERED - LCSC C5249699 out of stock; source from Digi-Key/Mouser instead
F_ESC1-8 (fuse element) | 30A mini blade fuse | N/A - not soldered; plugs into holder | 8 | 16 | Loose automotive part | Non-LCSC (auto parts/RC supplier)
R_BLEED1 | 22k Ohm (RC0603FR-0722KL - Yageo) | Resistor_SMD:R_0603_1608Metric_Pad0.98x0.95mm_HandSolder | 1 | 0 | 0603 | NOT ORDERED - LCSC C114065 requires Min:100/Mult:100; ask around for spares instead
R_LED1 | 10k Ohm (RC0603FR-0710KL - Yageo) | Resistor_SMD:R_0603_1608Metric_Pad0.98x0.95mm_HandSolder | 1 | 0 | 0603 | NOT ORDERED - LED already owned, and LCSC C98220 requires Min:100/Mult:100
R_PWM1, R_PWM2, R_PWM3, R_PWM4, R_PWM5, R_PWM6, R_PWM7, R_PWM8 | 100 Ohm | Resistor_SMD:R_0402_1005Metric_Pad0.72x0.64mm_HandSolder | 8 | 0 | 0402 | ALREADY OWNED (sample book) - not ordering
R_PD1, R_PD2, R_PD3, R_PD4, R_PD5, R_PD6, R_PD7, R_PD8 | 10k Ohm (RC0603FR-0710KL - Yageo) | Resistor_SMD:R_0603_1608Metric_Pad0.98x0.95mm_HandSolder | 8 | 0 | 0603 | NOT ORDERED - LCSC C98220 requires Min:100/Mult:100; ask around for spares instead

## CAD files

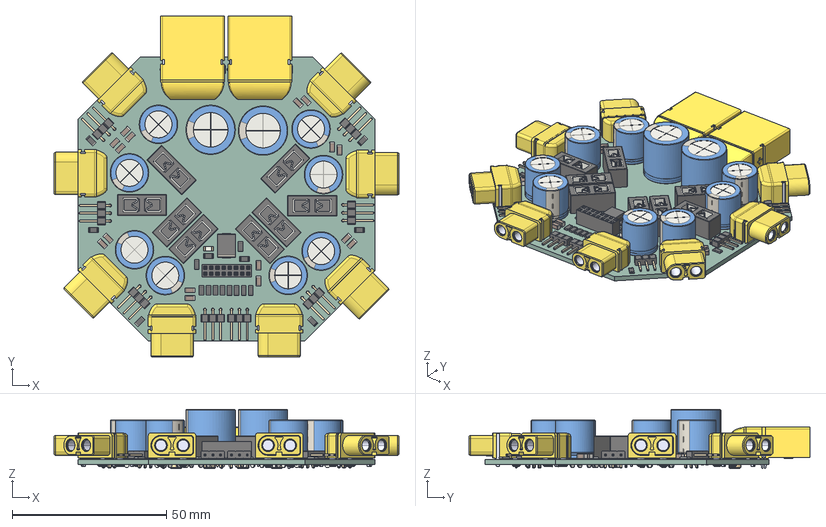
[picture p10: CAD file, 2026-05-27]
SwimBladderV1.0.step
111.9 x 110.7 x 19.2 mm
Fuseholder_Blade_Mini_Keystone_3568 x 8
PinHeader_1x03_P2.54mm_Horizontal x 8
C_1206_3216Metric x 16
R_1206_3216Metric x 18
XT60PW-F_XT60PW-F x 8
XT90PW-M--3DModel-STEP-56544 x 2
CP_Radial_D12.5mm_P5.00mm x 8
PinSocket_2x08_P2.00mm_Vertical
CP_Radial_D16.0mm_P7.50mm x 2
LED_1206_3216Metric
D_SMC
UWU PDB_PCB

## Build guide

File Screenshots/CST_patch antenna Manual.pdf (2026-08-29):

SUTD IEEE-HKN Mu Epsilon Chapter | CST Microwave Studio Tutorial

# CST MICROWAVE STUDIO TUTORIAL WORKSHOP

Manual version 1.4

Conducted by SUTD Student Chapter (Mu Epsilon) of IEEE–HKN (Eta Kappa Nu)

Lee Wei Jian,
EPD Senior Year Student

## Table of Contents

## Acknowledgements

This workshop manual is produced with feedbacks and contributions from the following individuals:

- Asst. Prof. Huang Shaoying, SUTD EPD Faculty Member
- Dr. Teo Tee Hui, SUTD EPD Faculty Member
- Ms. Chu Wenjing, SUTD ARMS Senior Lab Technologist
- Mr. Nyan Lin Htet, SUTD ARMS Lab Technologist
- Ms. Elizaveta Motovilova, SUTD EPD PhD Student
- Mr. Ang Yi Liang, SUTD Fabrication Laboratory Lab Technologist
- Mr. Tiong Wei Li, SUTD ESD Undergraduate Student
- Mr. Sabareesh M Nair, SUTD EPD Undergraduate Student
- Mr. Stanley Loh Qing Shui, SUTD EPD Undergraduate Student

The SUTD IEEE-HKN Student Chapter (Mu Epsilon) greatly appreciate their inputs for this workshop manual.

## Introduction

CST Microwave Studio (CST MWS) is a specialist tool for the 3D EM simulation of high frequency components. CST MWS enables the fast and accurate analysis of high frequency (HF) devices such as antennas, filters, couplers, planar and multi-layer structures and SI and EMC effects. Exceptionally user friendly, CST MWS quickly gives you an insight into the EM behavior of your high frequency designs.

This tutorial aims to educate on using the CST Microwave Studio software to design a WiFi Patch Antenna. There are a total of five parts to this tutorial:
1. Creating the Design project file
2. Modelling of WiFi Patch Antenna
3. Inset Fed Patch Antenna Simulation and Results
4. Parameter Sweeping
5. Generating 2D DXF and 2D Gerber files for PCB Milling Machine

At the end of the tutorial, user should be able to fabricate an actual WiFi Patch Antenna by using the LPKF PCB milling machine in the SUTD Fab Lab with assistance from the CST Microwave Studio software.

Microstrip or patch antennas are becoming increasingly useful because they can be printed directly onto a circuit board. Microstrip antennas are becoming very widespread within the mobile phone market. Patch antennas are low cost, have a low profile and are easily fabricated. The size of a microstrip antenna is inversely proportional to its frequency. At frequencies lower than microwave, microstrip patches don't
make | sense | because | of | the | sizes | required. | Microwaves are | forms | of electromagnetic
radiation with wavelengths ranging from one meter to one millimeter; with frequencies between 300 MHz (100 cm) and 300 GHz (0.1 cm).

Size of Microstrip Antenna ∝

| | | | | | | 1
Frequency

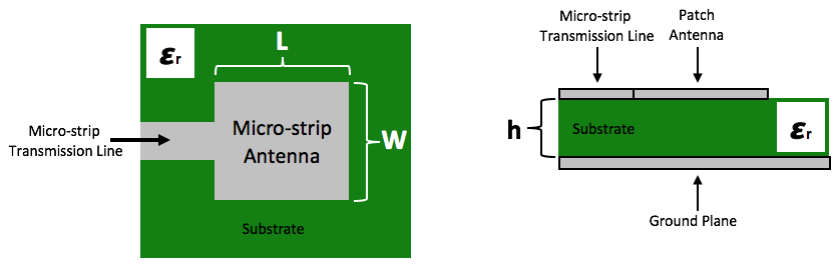
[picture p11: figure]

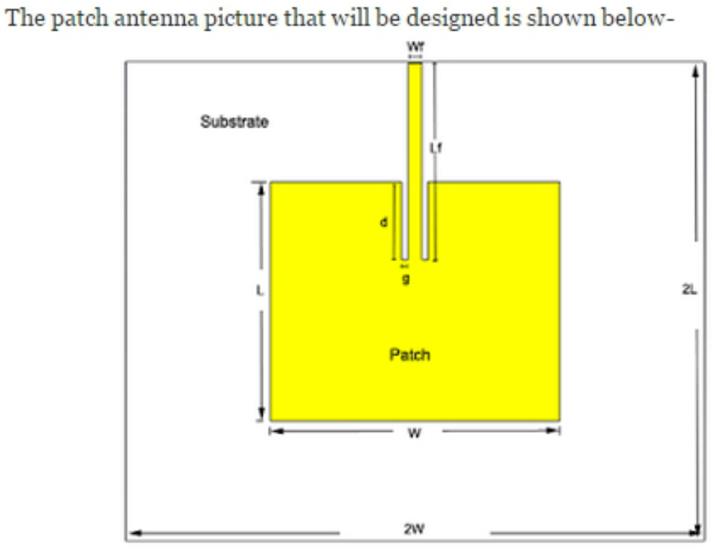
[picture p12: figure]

Advantages of microstrip antennas include:
- Low cost to fabricate.
- Conformal structures are possible (it's easy to form curved surfaces, as long as the curve is in one direction only).
- Easy to form a large array, spaced at half-wavelength or less.
- Light weight.

Disadvantages include:
- Limited bandwidth. (A bandwidth is a measurement of the width of a range of frequencies, measured in hertz.)
- Low power handling.

In circuit theory, the impedance is a generalization of electrical resistivity in the case of alternating current, and is measured in ohms. Impedance is the complex-valued generalization of resistance. The impedance of an ideal resistor is purely real and is referred to as a resistive impedance:

Ideal inductors and capacitors have a purely imaginary reactive impedance:

The impedance of inductors increases as frequency increases:

The impedance of capacitors decreases as frequency increases:

Impedance matching is important when components of an electric circuit are connected (waveguide to antenna for example): The impedance ratio determines how much of the wave is transmitted forward and how much it is reflected. The reflection coefficient can be calculated using:

, where | is the reflection coefficient (0 denotes full transmission, 1 full reflection, and 0.5 is a reflection
of half the incoming voltage), | and | are the impedance of the first component (from which the wave
enters) and the second component, respectively. An impedance mismatch creates a reflected wave.

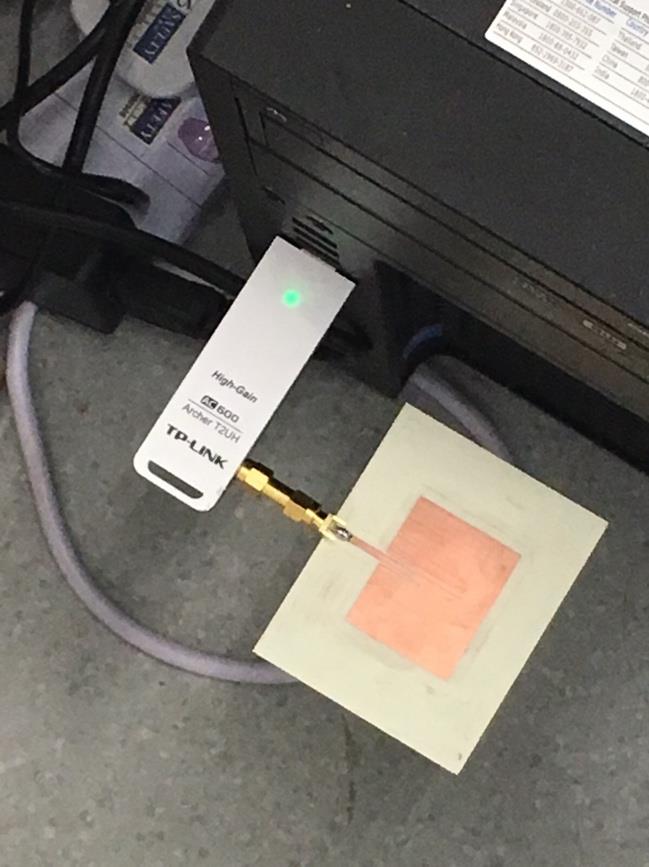
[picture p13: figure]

## Part I: Creating the Design project file

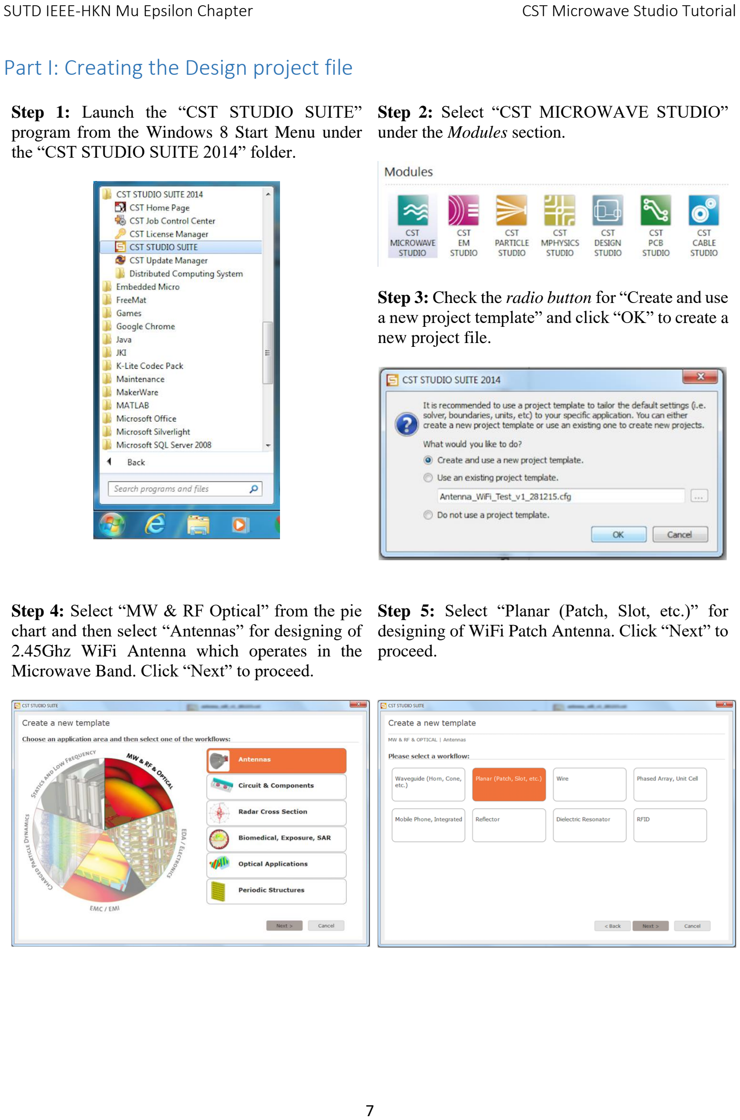
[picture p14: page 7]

Step 1: Launch the “CST STUDIO SUITE” program from the Windows 8 Start Menu under the “CST STUDIO SUITE 2014” folder.
Step 2: Select “CST MICROWAVE STUDIO” under the Modules section.
Step 3: Check the radio button for “Create and use a new project template” and click “OK” to create a new project file.
Step 4: Select “MW & RF Optical” from the pie chart and then select “Antennas” for designing of 2.45Ghz WiFi Antenna which operates in the Microwave Band. Click “Next” to proceed.
Step 5: Select “Planar (Patch, Slot, etc.)” for designing of WiFi Patch Antenna. Click “Next” to proceed.

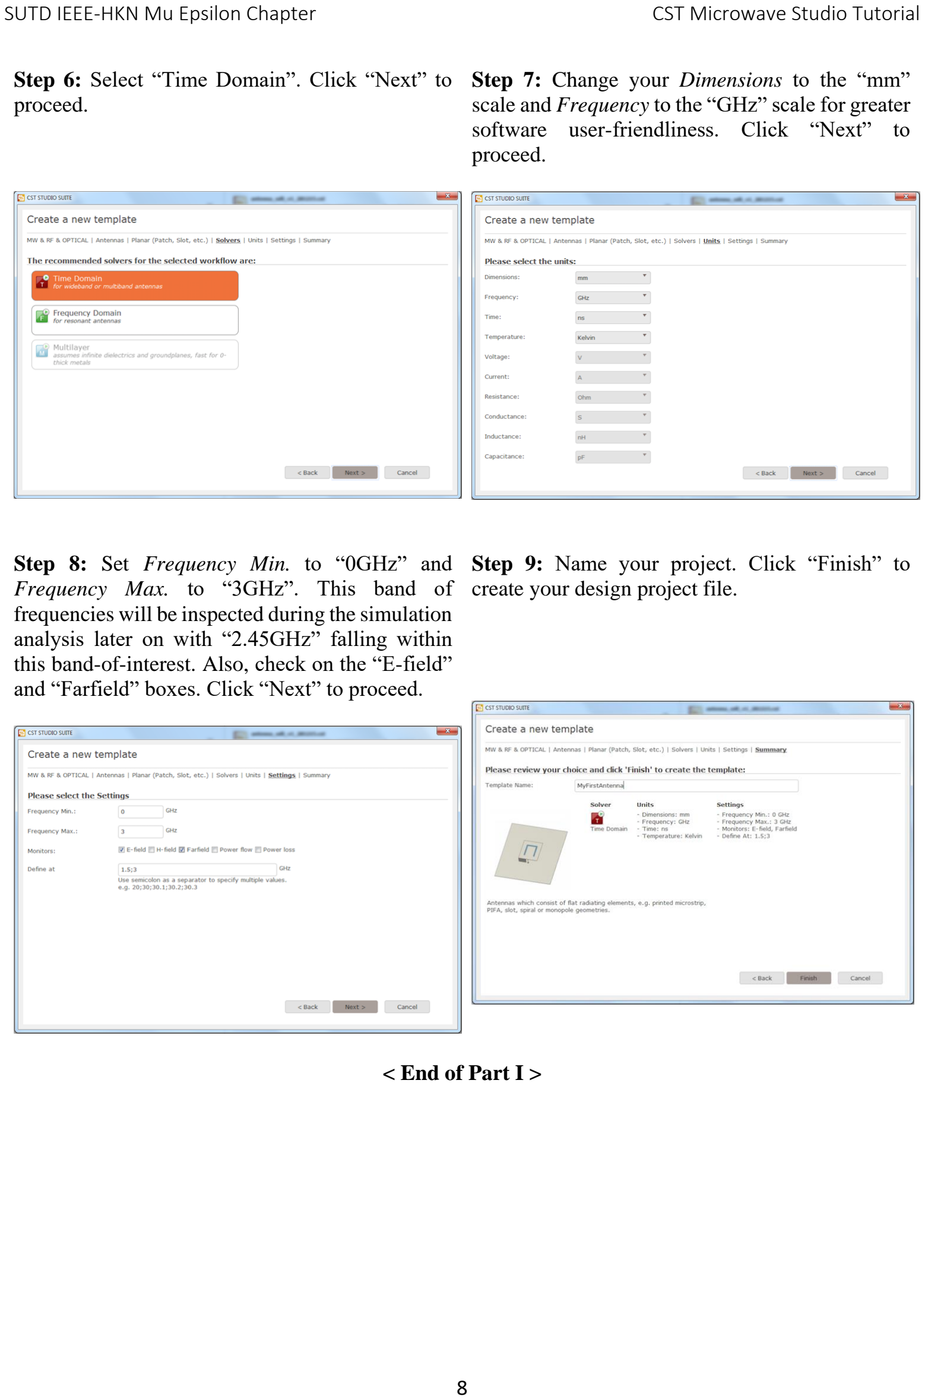
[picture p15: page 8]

Step 6: Select “Time Domain”. Click “Next” to proceed.
Step 7: Change your Dimensions to the “mm” scale and Frequency to the “GHz” scale for greater software user-friendliness. Click “Next” to proceed.
Step 8: Set Frequency Min. to “0GHz” and Frequency Max. to “3GHz”. This band of frequencies will be inspected during the simulation analysis later on with “2.45GHz” falling within this band-of-interest. Also, check on the “E-field” and “Farfield” boxes. Click “Next” to proceed.
Step 9: Name your project. Click “Finish” to create your design project file.

< End of Part I >

## Part II: Modelling of WiFi Patch Antenna

Step 1: W and L are the width and length of the WiFi Patch Antenna. The substrate has twice the width and length of the patch antenna, that is, 2W and 2L. Wf and Lf are the dimensions of the microstrip line. “d” is the inset fed distance and “g” is the gap between the patch antenna and the microstrip feed line.
Step 2: Go on to https://www.pasternack.com/t-calculator-microstrip-ant.aspx (https://www.pasternack.com/t-calculator-microstrip-ant.aspx) to auto-generate the width (W) and length (L) of the WiFi Patch Antenna according to the parameters of our purchased PCB laminate.

RO4350 Laminate
Dielectric Constant: 3.48
Dielectric Height (Thickness): 0.762mm Operation Frequency: 2.45GHz

Next, under Parameter List (near the bottom left-hand corner of the screen), define the following variables of the WiFi Patch Antenna. Theories and formula related to the following parameters will be covered in greater details during undergraduate level engineering programme in SUTD (course 30.102: Electromagnetics and Applications). Do not forget to fill in the red boxes below with your auto generated L and W values.

## Creating the Substrate

Step 3: From the Modelling section of the CST program, select the “Brick” icon and press “ESC” on your keyboard. This will bring up a window that allows users to specify the dimensions of the substrate.

Give a name “Substrate” and enter the following:

Length (Xmin = -L, Xmax = L) Width (Ymin = -W, Ymax = W) Height (Zmin = 0, Zmax = h)

From the dropdown menu of the Material section, select “Load from Material Library” and search for Rogers RO4350 (lossy). Press “Load” and then “OK” to complete the substrate definition. Now, the substrate will appear on the screen.

## Creating the Ground Plane

Step 4: Rotate the substrate to show the back face of it. To enter the “Rotate” mode, right click on the screen and select “Rotate”.

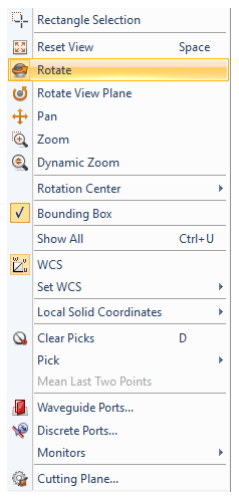
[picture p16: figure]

From the Modelling section of the CST program, under “Picks”, select “Pick Face”. Double click on the back face of the substrate to Pick this back face. Once the back face is highlighted, from the Modelling section of the CST program, click “Align WCS” to shift the drawing/modelling reference on to the back face of the substrate.

Step 5: Again, from the Modelling section of the CST program, under “Picks”, select “Pick Face” and pick the back face of the substrate by double clicking on this back face of the substrate. Now, select the “Extrude” icon under the “Brick” icon. Name the new surface that will be extruded as “Ground Plane” then enter the Height as “ t ” and from the dropdown menu of the Material section, select “Load from Material Library” and search for Copper (annealed). Press “Load” and then “OK” to complete the ground plane definition. Now, the ground plane will be extruded from the substrate.

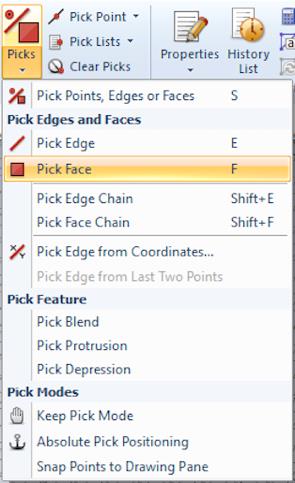
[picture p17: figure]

## Creating the Patch Antenna

Step 6: Rotate the substrate to show the top face of it. From the Modelling section of the CST program, under “Picks”, select “Pick Face”. Pick the top face of the substrate. Once the top face is highlighted, from the Modelling section of the CST program, click “Align WCS” to shift the drawing/modelling reference on to the top face of the substrate.

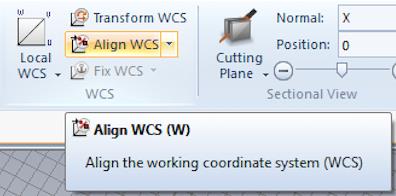
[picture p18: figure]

Step 7: From the Modelling section of the CST program, select the “Brick” icon and press “ESC” on your keyboard.

Give a name “Patch Antenna” and enter the following:

Length (Umin = -L/2, Umax = L/2) Width (Vmin = -W/2, Vmax = W/2) Height (Wmin = 0, Wmax = t)

From the dropdown menu of the Material section, select “Load from Material Library” and search for Copper (annealed). Press “Load” and then “OK” to complete the patch antenna definition. Now, the patch antenna will be built on the top face of the substrate.

## Creating the Microstrip Feed Line

Step 8: To create a microstrip feed line, first an empty space will need to be created before adding in the microstrip feed line. This creates a gap between the microstrip feed line and the patch antenna. From the Modelling section of the CST program, select the “Brick” icon and press “ESC” on your keyboard.

Give a name “substractor” and enter the following:

Length (Umin = L/2-d, Umax = L/2) Width (Vmin = -(Wf/2+g), Vmax = Wf/2+g) Height (Wmin = 0, Wmax = t)

From the dropdown menu of the Material section, select “Load from Material Library” and search for Nickel (or any default material. It doesn’t matter which material you are using). Press “Load” and then “OK” to complete the substractor definition.

Once the above is done, a Shape Intersection window will appear because the newly created “substractor” shape has intersected with the “Patch Antenna” shape. Check the “Cut away highlighted shape” radio button and create the empty space.

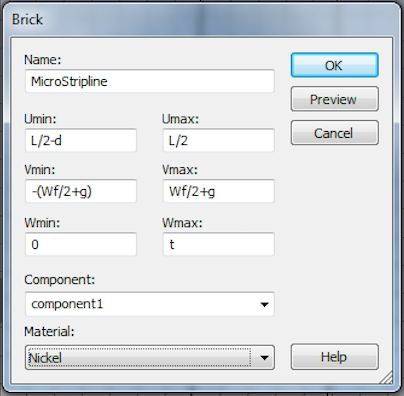
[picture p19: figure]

Step 9: From the Modelling section of the CST program, select the “Brick” icon and press “ESC” on your keyboard.

Give a name “microstripline” and enter the following:

Length (Umin = L/2-d, Umax = L) Width (Vmin = -Wf/2, Vmax = Wf/2) Height (Wmin = 0, Wmax = t)

From the dropdown menu of the Material section, select Copper (annealed). Press “OK” to complete the microstrip feed line definition. Now, the microstrip feed line will be built on the top face of the substrate.

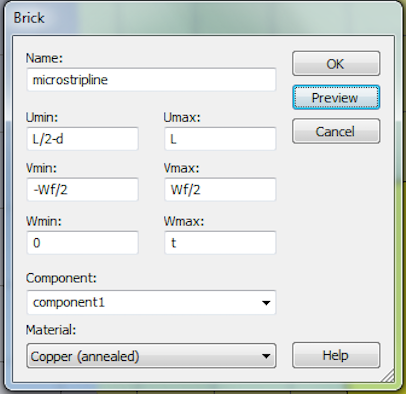
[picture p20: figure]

## Merging the Patch Antenna with the Microstrip Feed Line

Step 10: Under Navigation Tree (on the left-hand side of the screen), expand “Components” >>> “component1” and single click on “Patch Antenna”. From the Modelling section of the CST program, under “Boolean”, select “Add” and then, single click on “ microstripline ”. Hit “Enter” on your keyboard to merge the patch antenna shape and microstrip feed line shape into a single shape. The final design is shown below.

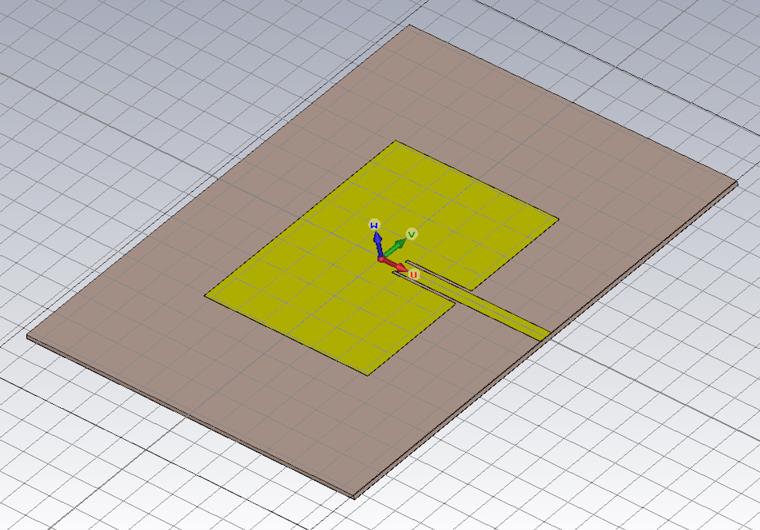
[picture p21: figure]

< End of Part II >

## Part III: Inset Fed Patch Antenna Simulation and Results

Step 1: From the Modelling section of the CST
program, under “Picks”, select “Pick Face”. Pick
the face shown in red below. This is the face where the waveguide port will operate. In this case, it is the face of the microstrip feed line where the signal will enter.
Step 2: From the Simulation section of the CST program, select “Waveguide Port”. A window will be opened for setting up of port dimensions.

Set:
Ymin = Wf/2+5*h, Ymax = Wf/2+5*h, Zmin = h, Zmax = 5*h

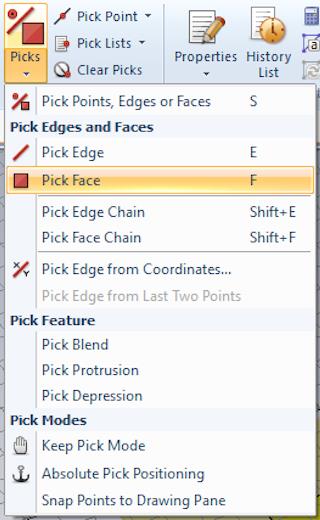
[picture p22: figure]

Leave other settings as default as shown in the figure below. Click “OK” to achieve the port in red below.

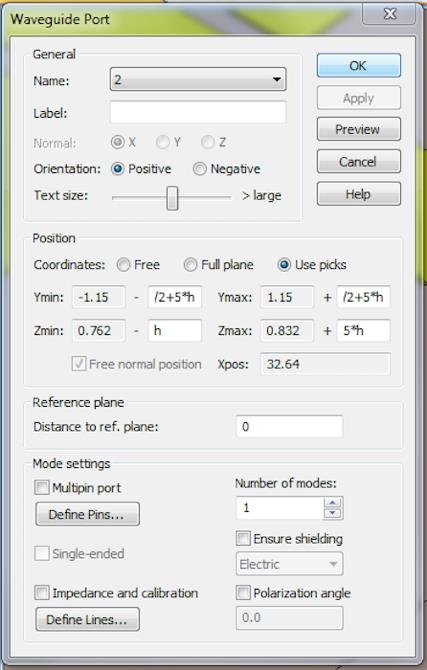
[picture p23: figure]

Step 3: For this workshop, we are (i) measuring the S11 or Return Loss and (ii) viewing the far field radiation from the 2.45Ghz WiFi Patch Antenna.

From the Simulation section of the CST program, click on “Field Monitor”. Then from the field monitor window, check the “Farfield/RCS” radio button and then set the frequency as 2.45Ghz. Click “Apply”.

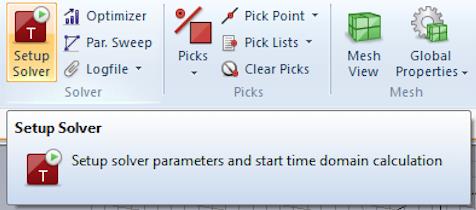
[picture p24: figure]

Next, check the “Electric energy density” radio button and then set the frequency as 2.45Ghz. Click “OK” to end the setup.

Step 4: From the Simulation section of the CST program, click on “Setup Solver”. This brings up the dialog box. While leaving all settings as default, click “Start” to start time domain calculation. This may take some time.

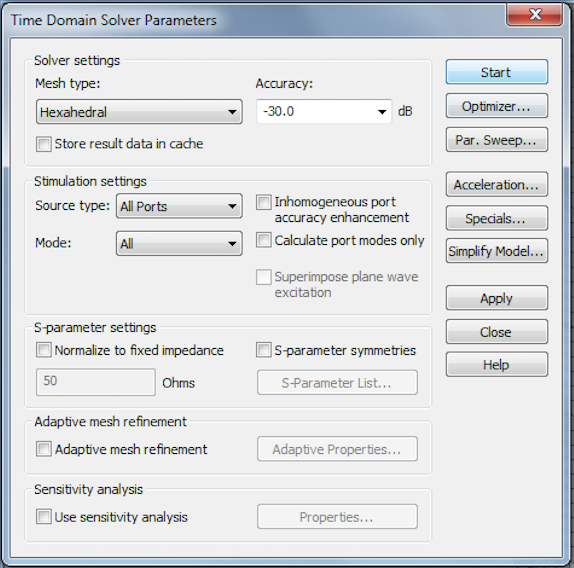
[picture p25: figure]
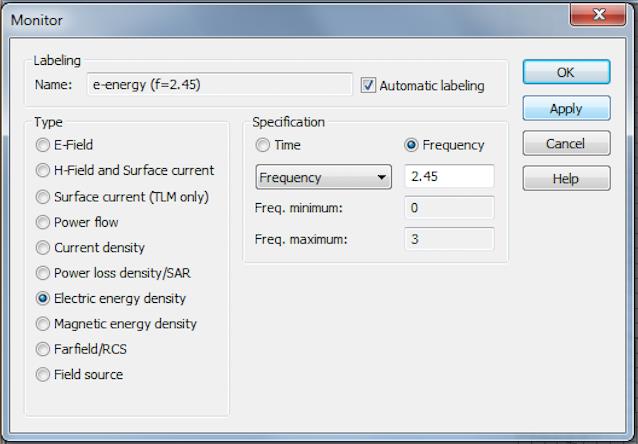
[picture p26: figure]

Step 5: Under Navigation Tree, select “1D Results” >>> “S-Parameters” >>> “S1,1”.

From the 1D Plot section of the CST program, select “Axis Marker” >>> “Move Marker to Minimum” to check the minimum value in the plot. For a good Return loss, the value should fall below -16dB to -20dB. The lower the return loss, the better the antenna.

Step 6: Under Navigation Tree, select “Farfields” >>> “farfield (f=2.45)”.

< End of Part III >

## Part IV: Parameter Sweeping

One of the techniques which allows us to improve on the simulated performance of the WiFi Antenna is to sweep a range of the controlled parameter(s) numerically (by brute force) to know the performance due to different values of the parameter(s) within the defined range. (Another technique is to use the “Optimizer” function from the Home section of the CST program.) We will now use the “Parameter Sweep” function.

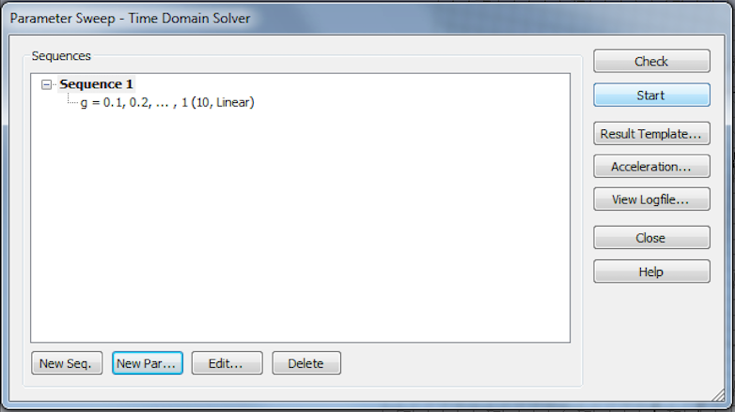
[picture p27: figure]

Step 1: From the Home section of the CST program, select “Par. Sweep”.

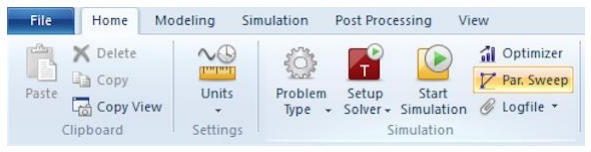
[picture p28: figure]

Step 2: Click “New Seq.” followed by “New Par…”.

Select “Name:” of the parameter to be “g” using the dropdown menu. We will tune the performance with “g”.

Select “Type:” to be “Linear sweep” using the dropdown menu.

Select “Define using:” to be “Step width” using the dropdown menu. For our preference, we will sweep from “0.1mm” to “1mm” with a Width step size of “0.1mm”. Note: A smaller step size will result in a longer solving time as the solving resolution is increased.

Step 3: Press “Start” to start evaluating the performance numerically according to different values of the parameters within the defined range set by you. This may take some time.
Step 4: Under Navigation Tree, select “1D Results” >>> “S-Parameters” >>> “S1,1”.

From the 1D Plot section of the CST program, select “Parametric Plot” to view the S11 performance due to the range of values of “g” all under one plot. From the plot, it can be concluded that g = 0.4mm provides the best performance. You may change the value of g from 1mm to 0.4mm from the Parameter List table.

Side note: You may try out the parameter sweep with other parameters in order to get better general performance.

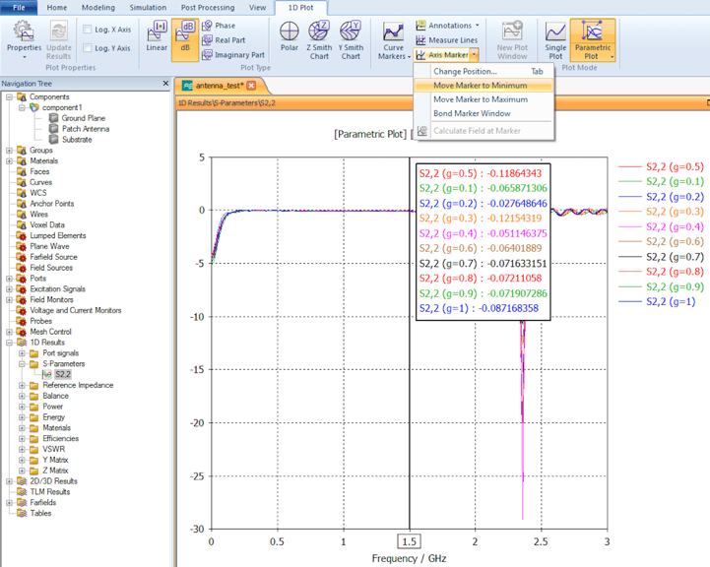
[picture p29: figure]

< End of Part IV >

## Part V: Generating 2D DXF and 2D Gerber files for PCB Milling Machine

We would like to generate the 2D DXF file to
allow the PCB Milling Machine to cut the PCB
laminate according to the perimeter of the antenna.
Step 1: Under Navigation Tree, select “Substrate”.
Step 2a: From the Modelling section of the CST

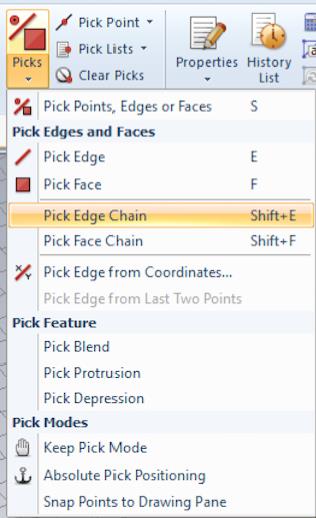
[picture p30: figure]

program, under “Picks”, select “Pick Edge Chain”. (You may select “Pick Edge” instead to select the 4 edges of the substrate material one-by-one, which is not recommended.)

Step 2b: Double click on the edge of the substrate material. The perimeter should be highlighted in red. Click “OK” to proceed.

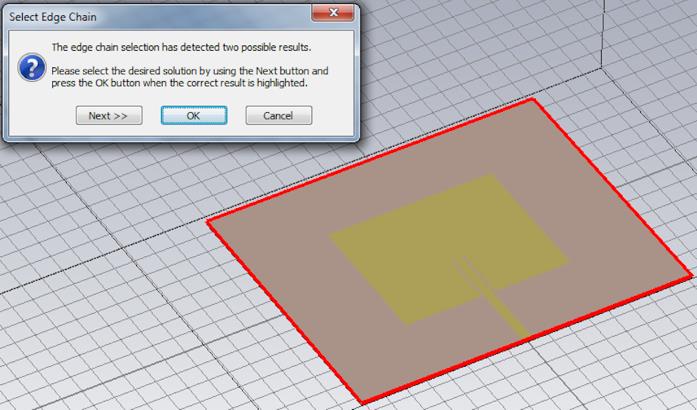
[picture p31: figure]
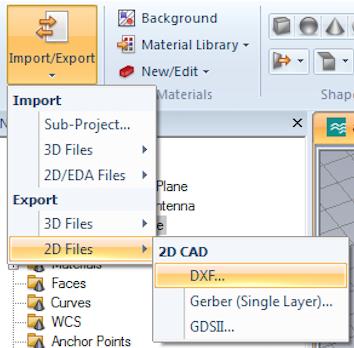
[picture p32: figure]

Step 3: From the Modelling section of the CST program, under “Import/Export”, select “2D Files” >>> “DXF…” to save the 2D DXF file of the substrate material to your desired location on the computer.

Lastly, we would like to generate the 2D Gerber file to allow the PCB Milling Machine to mill the necessary areas beside the actual patch antenna. The Gerber format is an open 2D binary vector image file format. It is the de facto standard used by printed circuit board (PCB) industry software to describe the printed circuit board images: copper layers, solder mask, legend, etc.

Step 4: From the Modelling section of the CST program, select “Clear Picks” to unpick the previous edges.
Step 5: Under Navigation Tree, select “Patch Antenna”.
Step 6a: From the Modelling section of the CST program, under “Picks”, select “Pick Face”.

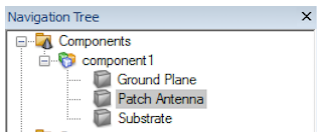
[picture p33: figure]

Step 6b: Double click on the face of the patch

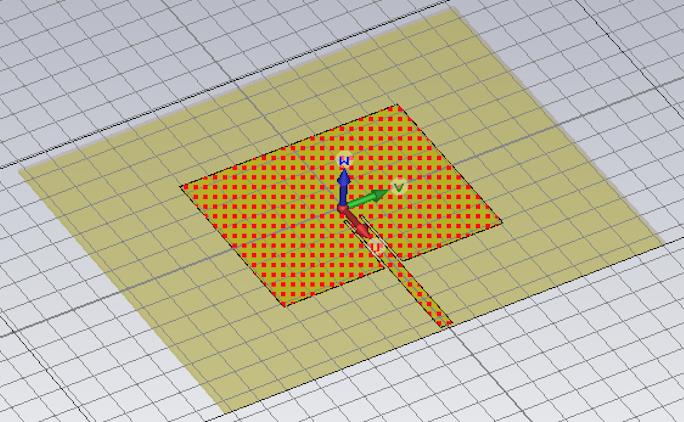
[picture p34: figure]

antenna. The patch antenna area should be highlighted in red.

Step 7: From the Modelling section of the CST

program, under “Import/Export”, select “2D Files” >>> “Gerber (Single Layer)…” to save the 2D Gerber (.gbr) file of the patch antenna to your desired location on the computer.

< End of Part V >

## Endnote

Users of CST Microwave Studio are given great flexibility in tackling a wide application range through the variety of available solver technologies. CST Microwave Studio is seen by an increasing number of engineers as an industry standard development tool.

For more details on how to utilize CST Microwave Studio, you may refer to the tutorial on http://eee.guc.edu.eg/Courses/Communications/COMM905%20Advanced%20Communication%20Lab/Sessions/MWS_Tutorials.pdf. (http://eee.guc.edu.eg/Courses/Communications/COMM905%20Advanced%20Communication%20Lab/Sessions/MWS_Tutorials.pdf)

## Reference

Bevelacqua, P. (n.d.). Antenna-Theory. Retrieved December 1, 2016, from http://www.antenna-theory.com/antennas/patches/antenna.php

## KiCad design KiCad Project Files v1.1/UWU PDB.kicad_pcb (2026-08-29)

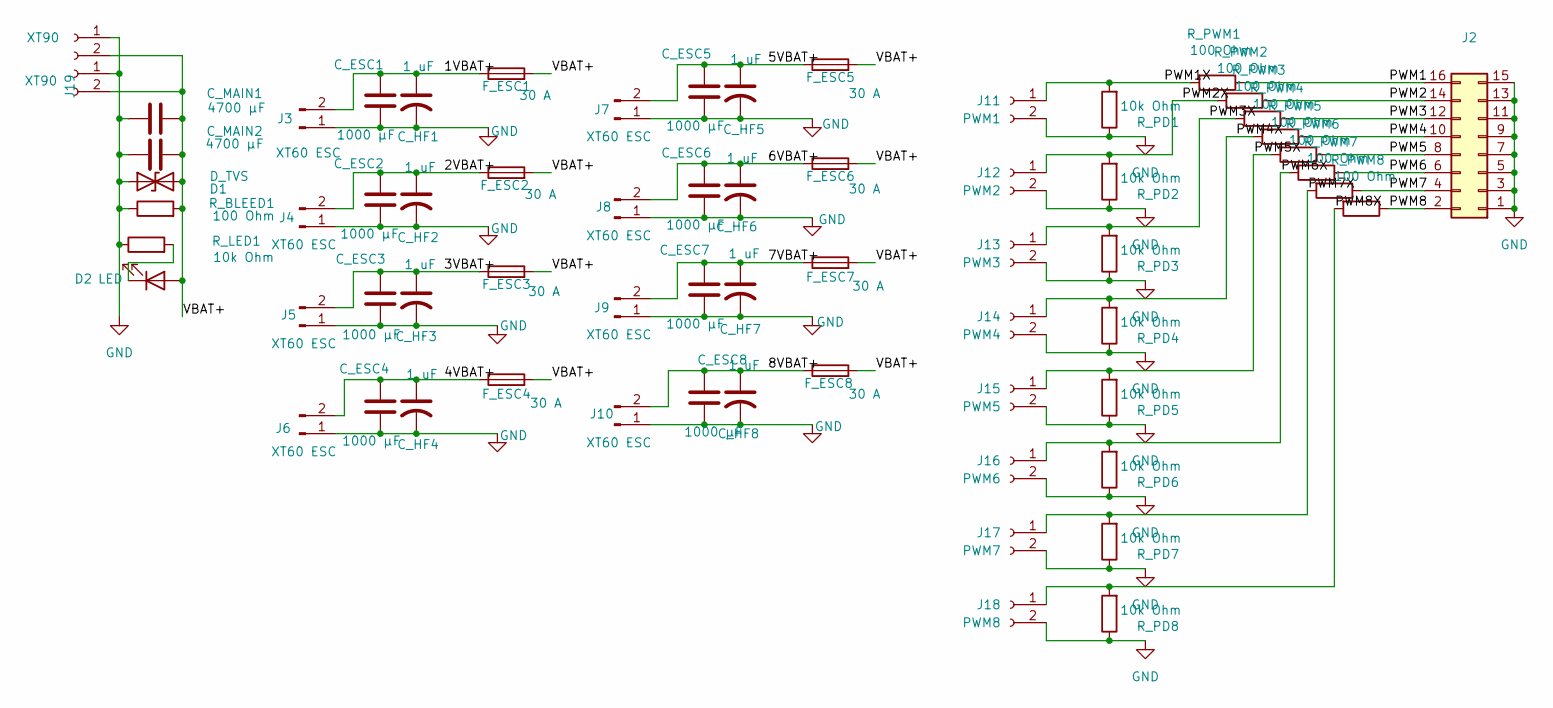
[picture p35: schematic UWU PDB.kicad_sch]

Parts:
C_ESC1, C_ESC2, C_ESC3, C_ESC4, C_ESC5, C_ESC6, C_ESC7, C_ESC8: 1000 µF; CP_Radial_D12.5mm_P5.00mm
C_HF1, C_HF2, C_HF3, C_HF4, C_HF5, C_HF6, C_HF7, C_HF8: 1 uF; C_0603_1608Metric_Pad1.08x0.95mm_HandSolder
C_MAIN1, C_MAIN2: 4700 µF; CP_Radial_D16.0mm_P7.50mm
D1: D_TVS; D_SMC
D2: LED; LED_1206_3216Metric
F_ESC1, F_ESC2, F_ESC3, F_ESC4, F_ESC5, F_ESC6, F_ESC7, F_ESC8: 30 A; Fuseholder_Blade_Mini_Keystone_3568
J1, J19: XT90; AMASS_XT90PW-M_1x02_P10.90mm_Horizontal
J2: Conn_02x08_Odd_Even; IDC-Header_2x08_P2.54mm_Vertical
J3, J4, J5, J6, J7, J8, J9, J10: XT60 ESC; AMASS_XT60PW-F_1x02_P7.20mm_Horizontal
J11: PWM1; Molex_Micro-Fit_3.0_43650-0200_1x02_P3.00mm_Horizontal
J12: PWM2; Molex_Micro-Fit_3.0_43650-0200_1x02_P3.00mm_Horizontal
J13: PWM3; Molex_Micro-Fit_3.0_43650-0200_1x02_P3.00mm_Horizontal
J14: PWM4; Molex_Micro-Fit_3.0_43650-0200_1x02_P3.00mm_Horizontal
J15: PWM5; Molex_Micro-Fit_3.0_43650-0200_1x02_P3.00mm_Horizontal
J16: PWM6; Molex_Micro-Fit_3.0_43650-0200_1x02_P3.00mm_Horizontal
J17: PWM7; Molex_Micro-Fit_3.0_43650-0200_1x02_P3.00mm_Horizontal
J18: PWM8; Molex_Micro-Fit_3.0_43650-0200_1x02_P3.00mm_Horizontal
R_BLEED1: 100 Ohm; R_0603_1608Metric_Pad0.98x0.95mm_HandSolder
R_LED1: 10k Ohm; R_0603_1608Metric_Pad0.98x0.95mm_HandSolder
R_PD1, R_PD2, R_PD3, R_PD4, R_PD5, R_PD6, R_PD7, R_PD8: 10k Ohm; R_0402_1005Metric_Pad0.72x0.64mm_HandSolder
R_PWM1, R_PWM2, R_PWM3, R_PWM4, R_PWM5, R_PWM6, R_PWM7, R_PWM8: 100 Ohm; R_0402_1005Metric_Pad0.72x0.64mm_HandSolder

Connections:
/1VBAT+: C_ESC1.1, C_HF1.1, F_ESC1.1, J3.2
/2VBAT+: C_ESC2.1, C_HF2.1, F_ESC2.1, J4.2
/3VBAT+: C_ESC3.1, C_HF3.1, F_ESC3.1, J5.2
/4VBAT+: C_ESC4.1, C_HF4.1, F_ESC4.1, J6.2
/5VBAT+: C_ESC5.1, C_HF5.1, F_ESC5.1, J7.2
/6VBAT+: C_ESC6.1, C_HF6.1, F_ESC6.1, J8.2
/7VBAT+: C_ESC7.1, C_HF7.1, F_ESC7.1, J9.2
/8VBAT+: C_ESC8.1, C_HF8.1, F_ESC8.1, J10.2
/PWM1: J2.16, R_PWM1.1
/PWM1X: J11.1, R_PD1.2, R_PWM1.2
/PWM2: J2.14, R_PWM2.1
/PWM2X: J12.1, R_PD2.2, R_PWM2.2
/PWM3: J2.12, R_PWM3.1
/PWM3X: J13.1, R_PD3.2, R_PWM3.2
/PWM4: J2.10, R_PWM4.1
/PWM4X: J14.1, R_PD4.2, R_PWM4.2
/PWM5: J2.8, R_PWM5.1
/PWM5X: J15.1, R_PD5.2, R_PWM5.2
/PWM6: J2.6, R_PWM6.1
/PWM6X: J16.1, R_PD6.2, R_PWM6.2
/PWM7: J2.4, R_PWM7.1
/PWM7X: J17.1, R_PD7.2, R_PWM7.2
/PWM8: J2.2, R_PWM8.1
/PWM8X: J18.1, R_PD8.2, R_PWM8.2
/VBAT+: C_MAIN1.1, C_MAIN2.1, D1.2 (A2), D2.2 (A), F_ESC1.2, F_ESC2.2, F_ESC3.2, F_ESC4.2, F_ESC5.2, F_ESC6.2, F_ESC7.2, F_ESC8.2, J1.2, J19.2, R_BLEED1.2
GND: C_ESC1.2, C_ESC2.2, C_ESC3.2, C_ESC4.2, C_ESC5.2, C_ESC6.2, C_ESC7.2, C_ESC8.2, C_HF1.2, C_HF2.2, C_HF3.2, C_HF4.2, C_HF5.2, C_HF6.2, C_HF7.2, C_HF8.2, C_MAIN1.2, C_MAIN2.2, D1.1 (A1), J1.1, J2.1, J2.3, J2.5, J2.7, J2.9, J2.11, J2.13, J2.15, J3.1, J4.1, J5.1, J6.1, J7.1, J8.1, J9.1, J10.1, J11.2, J12.2, J13.2, J14.2, J15.2, J16.2, J17.2, J18.2, J19.1, R_BLEED1.1, R_LED1.1, R_PD1.1, R_PD2.1, R_PD3.1, R_PD4.1, R_PD5.1, R_PD6.1, R_PD7.1, R_PD8.1
unnamed: D2.1 (K), R_LED1.2

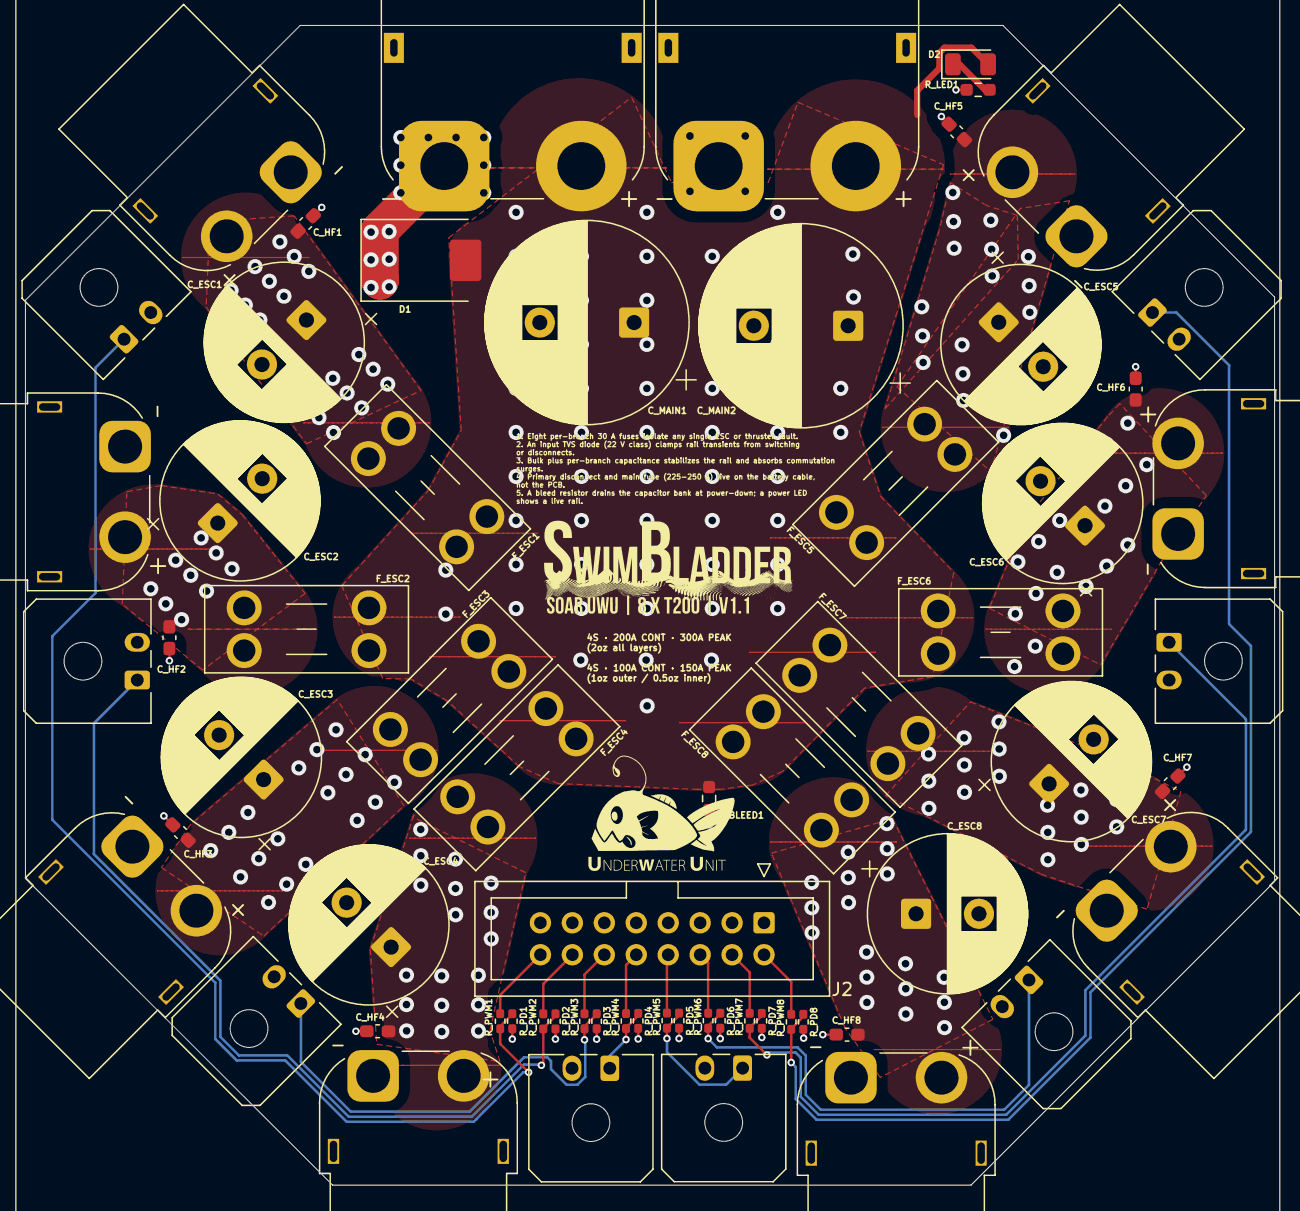
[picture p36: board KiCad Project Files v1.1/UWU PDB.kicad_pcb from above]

Board: 4 copper layers, 99.3 x 92.2 mm, 65 parts (0 on the bottom side), 27 nets.

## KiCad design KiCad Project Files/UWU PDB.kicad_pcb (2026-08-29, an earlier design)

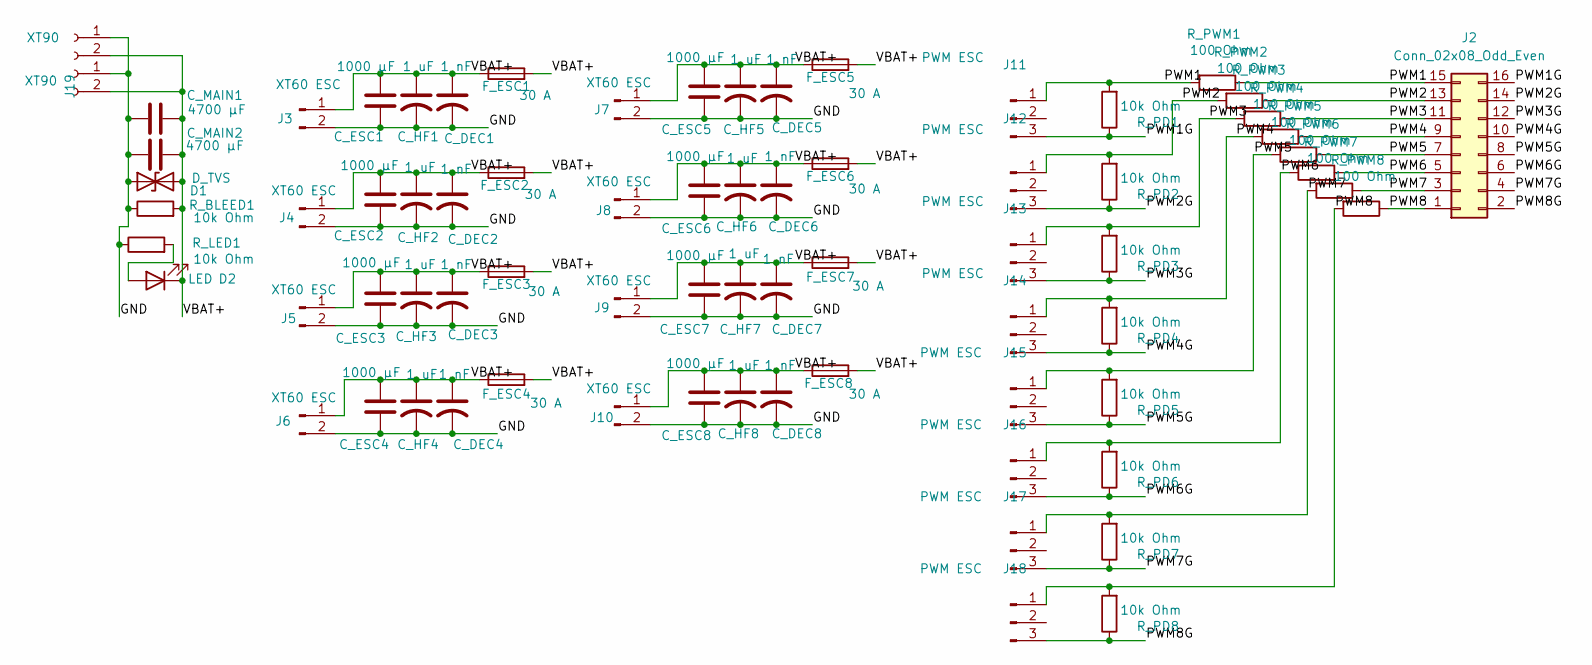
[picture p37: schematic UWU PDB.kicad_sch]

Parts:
C_DEC1, C_DEC2, C_DEC3, C_DEC4, C_DEC5, C_DEC6, C_DEC7, C_DEC8: 1 nF; C_1206_3216Metric_Pad1.33x1.80mm_HandSolder
C_ESC1, C_ESC2, C_ESC3, C_ESC4, C_ESC5, C_ESC6, C_ESC7, C_ESC8: 1000 µF; CP_Radial_D12.5mm_P5.00mm
C_HF1, C_HF2, C_HF3, C_HF4, C_HF5, C_HF6, C_HF7, C_HF8: 1 uF; C_1206_3216Metric_Pad1.33x1.80mm_HandSolder
C_MAIN1, C_MAIN2: 4700 µF; CP_Radial_D16.0mm_P7.50mm
D1: D_TVS; D_SMC
D2: LED; LED_1206_3216Metric
F_ESC1, F_ESC2, F_ESC3, F_ESC4, F_ESC5, F_ESC6, F_ESC7, F_ESC8: 30 A; Fuseholder_Blade_Mini_Keystone_3568
J1, J19: XT90; AMASS_XT90PW-M_1x02_P10.90mm_Horizontal
J2: Conn_02x08_Odd_Even; PinSocket_2x08_P2.00mm_Vertical
J3, J4, J5, J6, J7, J8, J9, J10: XT60 ESC; AMASS_XT60PW-F_1x02_P7.20mm_Horizontal
J11, J12, J13, J14, J15, J16, J17, J18: PWM ESC; PinHeader_1x03_P2.54mm_Horizontal
R_BLEED1: 10k Ohm; R_1206_3216Metric
R_LED1: 10k Ohm; R_1206_3216Metric
R_PD1, R_PD2, R_PD3, R_PD4, R_PD5, R_PD6, R_PD7, R_PD8: 10k Ohm; R_1206_3216Metric
R_PWM1, R_PWM2, R_PWM3, R_PWM4, R_PWM5, R_PWM6, R_PWM7, R_PWM8: 100 Ohm; R_1206_3216Metric

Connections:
/GND: C_DEC1.2, C_DEC2.2, C_DEC3.2, C_DEC4.2, C_DEC5.2, C_DEC6.2, C_DEC7.2, C_DEC8.2, C_ESC1.1, C_ESC2.1, C_ESC3.1, C_ESC4.1, C_ESC5.1, C_ESC6.1, C_ESC7.1, C_ESC8.1, C_HF1.2, C_HF2.2, C_HF3.2, C_HF4.2, C_HF5.2, C_HF6.2, C_HF7.2, C_HF8.2, C_MAIN1.2, C_MAIN2.2, D1.1 (A1), J1.1, J3.2, J4.2, J5.2, J6.2, J7.2, J8.2, J9.2, J10.2, J19.1, R_BLEED1.1, R_LED1.1
/PWM1: J2.15, J11.1, R_PD1.2, R_PWM1.1, R_PWM1.2
/PWM1G: J2.16, J11.3, R_PD1.1
/PWM2: J2.13, J12.1, R_PD2.2, R_PWM2.1, R_PWM2.2
/PWM2G: J2.14, J12.3, R_PD2.1
/PWM3: J2.11, J13.1, R_PD3.2, R_PWM3.1, R_PWM3.2
/PWM3G: J2.12, J13.3, R_PD3.1
/PWM4: J2.9, J14.1, R_PD4.2, R_PWM4.1, R_PWM4.2
/PWM4G: J2.10, J14.3, R_PD4.1
/PWM5: J2.7, J15.1, R_PD5.2, R_PWM5.1, R_PWM5.2
/PWM5G: J2.8, J15.3, R_PD5.1
/PWM6: J2.5, J16.1, R_PD6.2, R_PWM6.1, R_PWM6.2
/PWM6G: J2.6, J16.3, R_PD6.1
/PWM7: J2.3, J17.1, R_PD7.2, R_PWM7.1, R_PWM7.2
/PWM7G: J2.4, J17.3, R_PD7.1
/PWM8: J2.1, J18.1, R_PD8.2, R_PWM8.1, R_PWM8.2
/PWM8G: J2.2, J18.3, R_PD8.1
/VBAT+: C_DEC1.1, C_DEC2.1, C_DEC3.1, C_DEC4.1, C_DEC5.1, C_DEC6.1, C_DEC7.1, C_DEC8.1, C_ESC1.2, C_ESC2.2, C_ESC3.2, C_ESC4.2, C_ESC5.2, C_ESC6.2, C_ESC7.2, C_ESC8.2, C_HF1.1, C_HF2.1, C_HF3.1, C_HF4.1, C_HF5.1, C_HF6.1, C_HF7.1, C_HF8.1, C_MAIN1.1, C_MAIN2.1, D1.2 (A2), D2.1 (K), F_ESC1.1, F_ESC1.2, F_ESC2.1, F_ESC2.2, F_ESC3.1, F_ESC3.2, F_ESC4.1, F_ESC4.2, F_ESC5.1, F_ESC5.2, F_ESC6.1, F_ESC6.2, F_ESC7.1, F_ESC7.2, F_ESC8.1, F_ESC8.2, J1.2, J3.1, J4.1, J5.1, J6.1, J7.1, J8.1, J9.1, J10.1, J19.2, R_BLEED1.2
unnamed: D2.2 (A), R_LED1.2

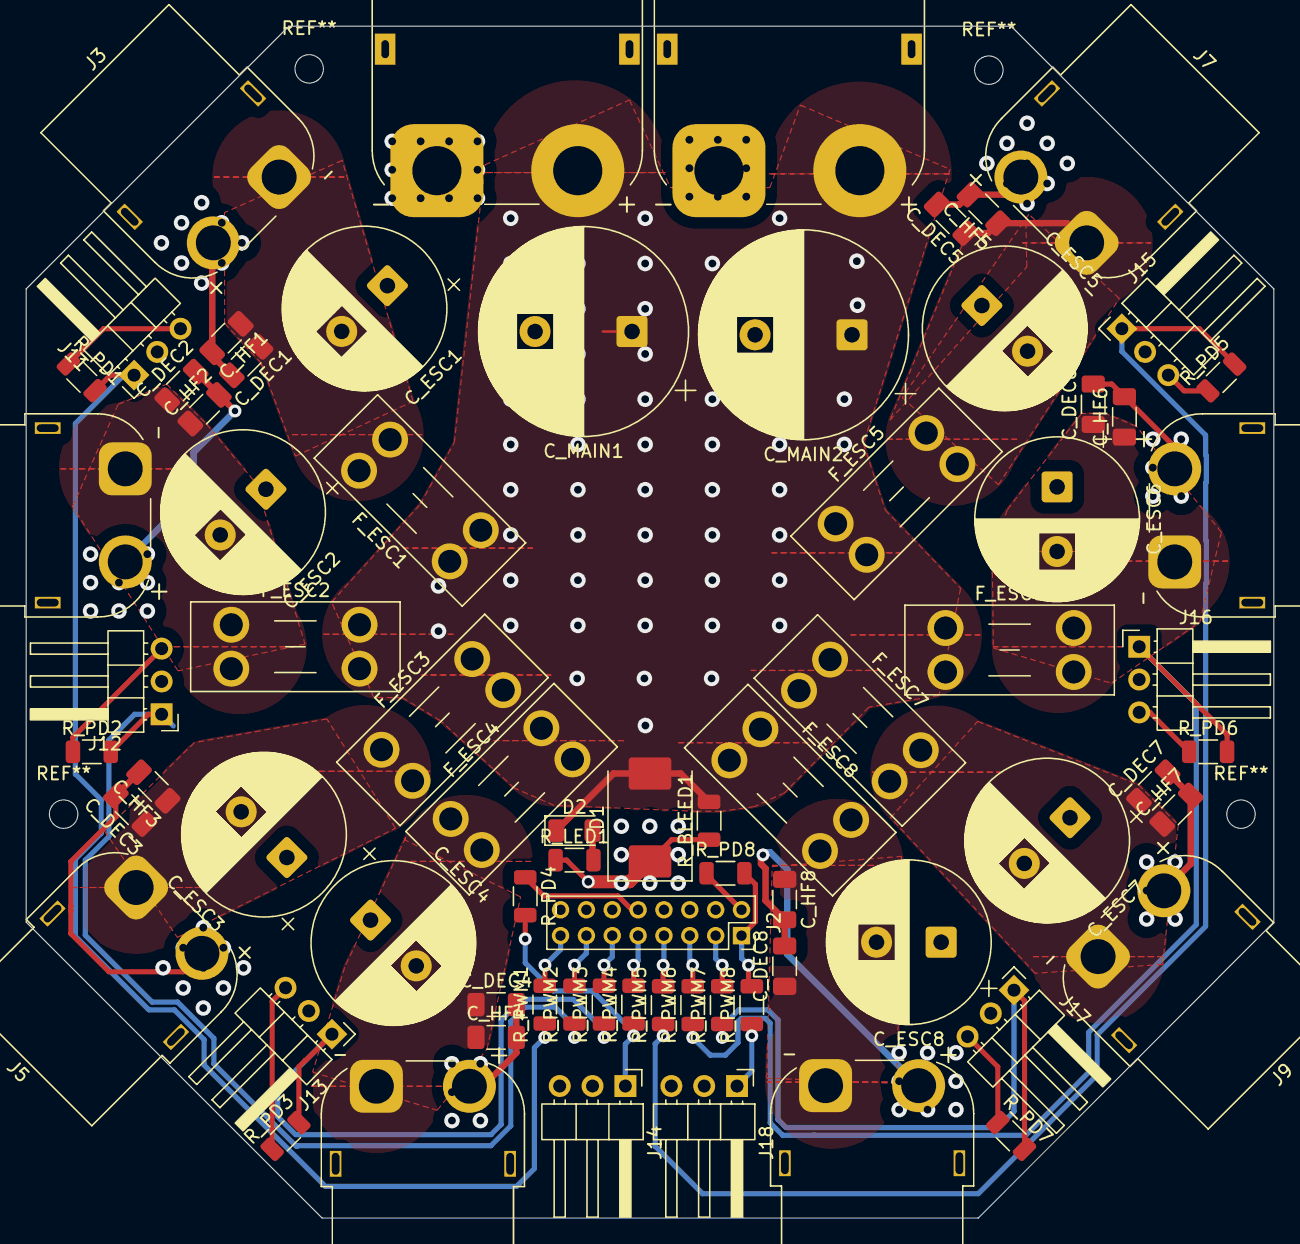
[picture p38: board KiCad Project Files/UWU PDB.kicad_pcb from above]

Board: 4 copper layers, 96.5 x 92.2 mm, 73 parts (0 on the bottom side), 19 nets.

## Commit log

2026-05-27 Initial commit: add README, LICENSE, and KiCad project files
    [SwimBladder PDB.kicad_sch, UWU PDB.kicad_pcb, UWU PDB.kicad_sch]
2026-05-27 Add SwimBladder V1.0 STEP model
    [SwimBladderV1.0.step]
2026-05-27 Update KiCad design files and refresh screenshots
    [UWU PDB.kicad_pcb, UWU PDB.kicad_sch]
2026-08-29 v1.1 PCB
    [UWU PDB.kicad_pcb, UWU PDB.kicad_sch]
2026-09-05 Update README, resolve R_BLEED1 value, add procurement BOMs
    - Set R_BLEED1 to 22k Ohm (was stale 3.3k in schematic, README said 100 Ohm)
    - Mark V1.1 known issues resolved in README
    - Add Procurement section with LCSC/JLC sourcing notes and a
    still-need-to-source checklist
    - Add SwimBladder_BOM_v1.1.csv (full reference BOM) and
    SwimBladder_LCSC_BatchBOM_v1.1.csv (LCSC batch-BOM upload, MOQ-adjusted
    for a 2-board build)
    [SwimBladder_BOM_v1.1.csv, SwimBladder_LCSC_BatchBOM_v1.1.csv, UWU PDB.kicad_sch]
2026-09-19 Remove schematic image from README screenshots section
2026-09-19 Add assembled board photos to README
    Feature the assembled PDB as the main image and add both photos plus a screenshots table for the render/routing images.
